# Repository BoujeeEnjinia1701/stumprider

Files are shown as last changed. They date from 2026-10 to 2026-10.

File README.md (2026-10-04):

# StumpRider

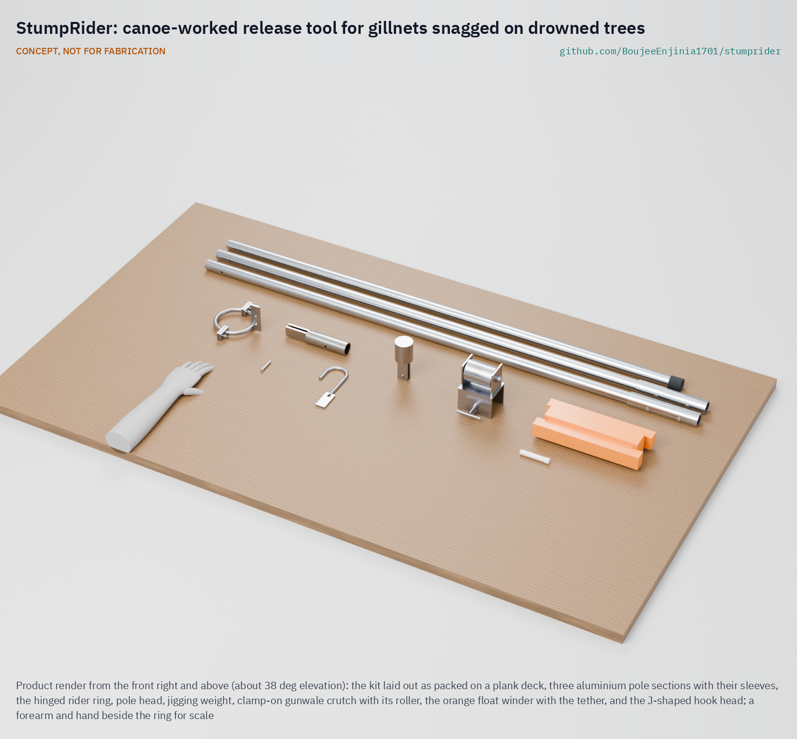
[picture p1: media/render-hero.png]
StumpRider: canoe-worked release tool for gillnets snagged on drowned trees


     

**Area:** Food and water security · **TRL:** 3 of 9 (proof of concept on paper) · **Value-engineering target:** USD 2,000 for the prototype work (estimated cost of the constructable design USD 299.50 for three kits and a bamboo pole) · **Difficulty:** 2 of 5

Frees gillnets snagged on submerged trees from the canoe so children are not sent to dive.

> CONCEPT, NOT FOR FABRICATION. StumpRider is a TRL 3 design on paper: it has not been built or tested, it is not certified equipment, and it never replaces a life jacket.

## Concept rationale

StumpRider is a release tool worked entirely from the canoe. A ring clips around the net line and slides down it onto the snag. The fisher pushes and works the ring with a pole until the net lifts clear of the branch. A shear pin in the pole head breaks at a set load, so a hard pull cannot capsize the canoe or tear the mesh; the pin is replaced and the fisher tries again from a different angle.

The design is deliberately simple: a hinged steel ring, a three-piece pole, a soft aluminium pin and some cord, all of which a village workshop can make and repair. The aim is not to improve the catch but to remove the one task that puts a child underwater. It is published as an open engineering reference so that NGOs, fisheries officers and boat builders can make it locally.

## Burning platform

Lake Volta in Ghana was formed over a flooded forest. It holds about 14 million cubic metres of submerged hardwood, and many trunks lurk just below the surface, where they snag fishermen's nets and hole canoes; stumps were the leading cause of documented boat accidents on the lake from 1990 to 2011, at 38 % ([Underwater timber harvesting on the Volta Lake, WMU](https://commons.wmu.se/cgi/viewcontent.cgi?article=1009&context=all_dissertations)). Child labour studies list the task directly: children dive into deep water to disentangle fishing nets from tree stumps, and small children have drowned doing it ([Analytical study on child labour in Lake Volta fishing, ILAB](https://www.dol.gov/sites/dolgov/files/ILAB/CHILD%20LABOUR%20IN%20VOLTA%20LAKE%20FISHING%20STUDY%20REPORT%20-%20FINAL%20REPORT.pdf)).

A 2024 prevalence study found that 15 % of children working in Lake Volta fishing reported diving underwater to retrieve nets, 37.7 % were likely victims of trafficking, and 5.1 % of parents and caregivers knew of a child who had died working on the lake ([IJM, 2024](https://ijmstoragelive.blob.core.windows.net/ijmna/documents/studies/2023-Fishing_Prevalence_Study_Report.pdf)). Enforcement and rescue matter most, but as long as nets snag, somebody is sent down. A tool that frees the net from the surface takes away the reason to send a child.

## Where it could be used

### By industry

| Industry | Use |
| --- | --- |
| Inland capture fisheries | Freeing gillnets and set lines snagged on drowned trees in reservoirs and lakes |
| Child protection and anti-trafficking programmes | A practical tool to hand out alongside rescue and awareness work, so boat owners have no excuse to send a child to dive |
| Fisheries extension and co-management | Safe-practice kits distributed through fisher associations and landing-site committees |
| Reservoir and dam operators | A low-cost measure for fishing communities on impoundments where forest was left standing |
| Recreational and research netting | Recovering survey nets and sampling gear from snag-rich water without divers |

### By country or region

| Country or region | Why it matters there |
| --- | --- |
| Ghana (Volta Lake) | About 14 million cubic metres of submerged trees snag nets and hole canoes ([WMU](https://commons.wmu.se/cgi/viewcontent.cgi?article=1009&context=all_dissertations)), and 15 % of children in the lake fishery report diving to retrieve nets ([IJM, 2024](https://ijmstoragelive.blob.core.windows.net/ijmna/documents/studies/2023-Fishing_Prevalence_Study_Report.pdf)). |
| Ghana (national) | An ILAB-funded study estimated over 49,000 children involved in fishing in Ghana, 87 % of them boys ([ILAB](https://www.dol.gov/sites/dolgov/files/ILAB/CHILD%20LABOUR%20IN%20VOLTA%20LAKE%20FISHING%20STUDY%20REPORT%20-%20FINAL%20REPORT.pdf)). |
| Zambia and Zimbabwe (Lake Kariba) | A large inshore gillnet fishery on a dammed reservoir, with around 1,200 fishers on the Zambian side by 1999 ([FAO](https://www.fao.org/4/y5056e/y5056e03.pdf)); whether snags drive diving there is an open question. |
| Low- and middle-income countries generally | Small-scale fisheries produce about 99.7 % of inland fisheries output and about 60 million people work in small-scale fishing ([Nature](https://www.nature.com/articles/s41586-024-08448-z)), so a hand tool that works in snag-rich water has a wide potential reach. |

## What sparked the idea

The idea came from the story of Foli, a boy enslaved on Lake Volta who was forced to dive into dark, murky water to untangle nets that caught on branches below the surface, even though he could not swim, until IJM social workers and local authorities took him off the canoe and arrested the boat master ([IJM](https://www.ijm.org/stories/foli)). The net had to come free somehow; the question was whether it could come free without a child going under.

## Problem

On lakes with drowned forests, gillnets catch on submerged trees and boat masters send children down to free them, sometimes children who cannot swim. Fishers have no simple tool that frees a snagged net from the canoe.

Full problem statement: [docs/01-problem.md](docs/01-problem.md)

## Concept

A release tool worked from the canoe that slides a ring down the net line onto the submerged snag and frees the gillnet with a pole and a shear pin, so fishers stop sending children to dive for it.

Full design precis: [docs/02-concept.md](docs/02-concept.md) · Requirements: [docs/03-requirements.md](docs/03-requirements.md) · Calculations: [docs/04-calcs/01-sizing.md](docs/04-calcs/01-sizing.md) · Prototype build plan: [docs/05-build-plan.md](docs/05-build-plan.md) · Design decisions: [docs/06-design-decisions.md](docs/06-design-decisions.md)

## Key components

- Rider ring: two hinged half rings of 12 mm steel bar, 100 mm inside, closed by a pinned gate
- Three-piece aluminium push pole, 4.18 m from the top hand to the ring, packing to 1.55 m
- Pole head with a fork over the ring's tang and a 2 mm soft aluminium shear pin (about 300 N)
- Spare shear pins from one calibrated reel
- 10 m tether cord on an orange foam float winder
- Jigging weight that pins to the ring for snags beyond pole reach
- Clamp-on gunwale crutch with a roller for the net line

## Building the prototype

The [prototype build plan](docs/05-build-plan.md) (SMR-BLD-001, plan, not yet built) is written for a village smith. It covers the kit component by component, with making sketches for the eleven made parts and the bamboo local variant pole, close-ups of eleven joints and a picture for each of twelve assembly steps. The steel parts are bent, cut, drilled and stick-welded, then galvanised; the pole is cut and drilled aluminium tube; everything is made in about a working day. No kit is used on a snag before its pin wire is calibrated on CalRig and a moored heel test shows the canoe stays within 5 deg, which is TRL 4 work.

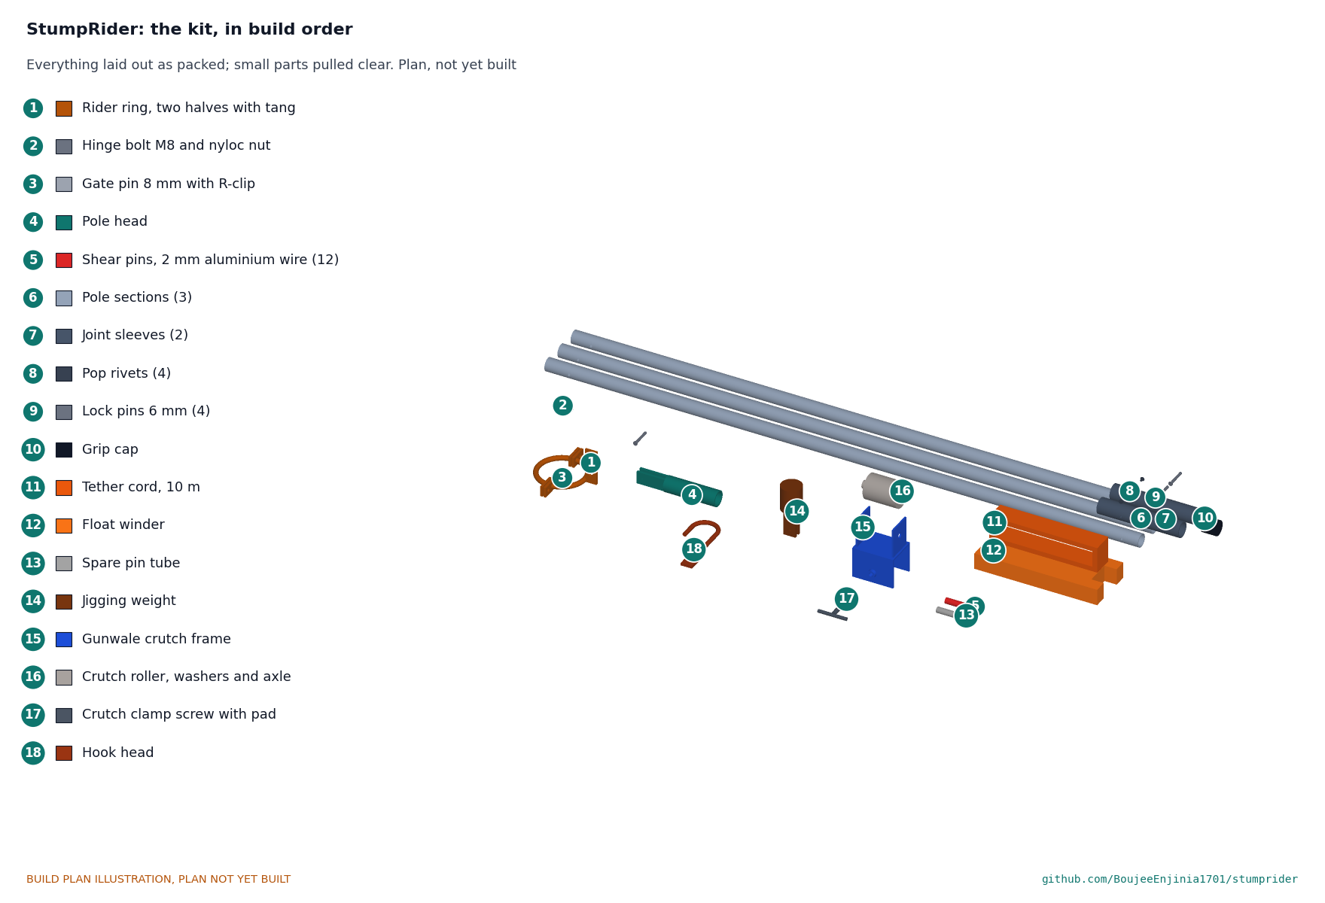
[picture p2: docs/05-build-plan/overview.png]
StumpRider build overview


## Safety

> Published as an open engineering reference, not certified equipment.
>
> The tool exists so that nobody enters the water; it must never be presented as a reason to keep children on boats.
>
> Crew wear life jackets while working a snag; the tool never replaces a life jacket.
>
> The shear pin is a safety device: always use the rated pin, never a nail or bolt substitute.
>
> Stop and cut the net rather than risk a capsize.
>
> The shear pin protects a canoe of about 8 m with three crew; it does not protect small dugouts. The tool is used only from canoes 7 m or longer with at least three crew, until heel tests set a pin for a smaller class, and the operator kneels.
>
> This design is published as an open engineering reference. It is not certified equipment.

## Repository layout

| Folder | Contents |
| --- | --- |
| `docs/` | Problem, concept, requirements, calculations and design decisions |
| `cad/src/` | build123d Python source, the source of truth for all geometry |
| `cad/step/`, `cad/stl/` | Exported models for FreeCAD, other CAD tools and printing |
| `cad/drawings/` | 2D sketches and dimensioned drawings |
| `bom/` | Bill of materials |
| `electronics/` | KiCad schematics and PCB layouts |
| `firmware/` | Microcontroller code |
| `media/` | Renders, perspectives and photos |
| `build-log/` | Dated prototyping notes |

## Documentation

Controlled documents follow the portfolio [documentation standard](.kit/STANDARDS.md). Each carries a document ID (SMR-PRC-001 for the precis), a version and a revision history. Branded PDFs are built with `python .kit/render.py` and attached to GitHub Releases when a document is tagged, for example `SMR-PRC-001/v1.0`.

## Credits

Designed by Amish Chadha at Design Molecule Labs. See [CONTRIBUTORS.md](CONTRIBUTORS.md) for roles. To cite this design, use [CITATION.cff](CITATION.cff) (GitHub shows it as "Cite this repository").

AI assistance (Claude) was used to accelerate prototype documentation and first-pass research. Design direction and all decisions are Amish Chadha's, recorded in this repository's decision records (`docs/decisions/`).

## Licenses

- **Hardware** (CAD, drawings, BOM, electronics): [CERN-OHL-S v2](LICENSE)
- **Software** (firmware, scripts, notebooks): [MIT](LICENSE-SOFTWARE)

A project of the [Design Molecule](https://designmolecule.com) lab.

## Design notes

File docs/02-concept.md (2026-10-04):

---
doc_id: SMR-PRC-001
title: StumpRider design precis
project: StumpRider
doc_type: Precis
version: "0.4"
status: Draft
date: '2026-10-03'
author: Amish Chadha
license: CERN-OHL-S-2.0
revisions:
- version: "0.1"
  date: '2026-09-30'
  author: Amish Chadha
  change: Initial scaffold
- version: "0.2"
  date: '2026-10-03'
  author: Amish Chadha
  change: TRL 2 precis; how it works, components with BOM numbers, key design choices, first-order numbers, safety, open questions
- version: "0.3"
  date: '2026-10-03'
  author: Amish Chadha
  change: TRL 3; constructable design of SMR-DDR-002 and figures from SMR-CAL-001
- version: "0.4"
  date: '2026-10-03'
  author: Amish Chadha
  change: Amish's decisions of 2026-10-03 (SMR-DDR-003); hook head, small-canoe rule, carried kit, bamboo local variant; figures from SMR-CAL-001 v0.2
---

# StumpRider design precis

Frees gillnets snagged on submerged trees from the canoe so children are not sent to dive.

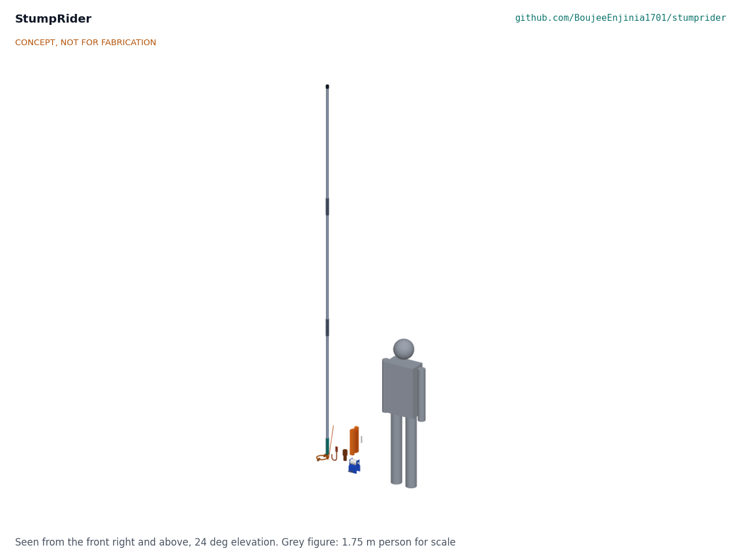
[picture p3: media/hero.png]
StumpRider concept: the tool beside a 1.75 m person, with the gunwale crutch, float winder and jigging weight


*Figure 1. The kit (concept render, CONCEPT, NOT FOR FABRICATION).*

> **Safety:** StumpRider exists so that nobody enters the water. It must never be presented as a reason to keep children on boats, and it never replaces a life jacket. Working a snag pulls the canoe over; the shear pin breaks before the pull can heel the design canoe more than about 4 deg, but small dugouts are not covered (see Safety). Stop and cut the net rather than risk a capsize.

## How it works

The crew pulls the net line up over the gunwale crutch and holds it taut above the snag. The operator, kneeling near the bow, opens the gate of the rider ring, closes the ring round the line and pushes it down the line with the jointed pole until it seats on the branch. The crew then slackens the line and the operator lifts, twists and pushes the ring along the branch until the mesh lifts clear. The pole head grips the ring by a fork on a tang, joined only by a 2 mm soft aluminium shear pin; if the pull or push goes above about 300 N (67 lbf), the pin breaks and the pole comes away. The ring stays on the net line and is recovered on its tether cord, a new pin is fitted, and the operator tries a different angle. For snags beyond the pole's reach, the pole head is taken off, the jigging weight is pinned to the tang in its place, and the ring is run down the line on its tether and jigged, as angling retrievers do.

## Components

*Table 1. Components (numbers are BOM lines in `bom/bom.csv`).*

| # | Component | Role | Made or bought |
| --- | --- | --- | --- |
| 1 | Rider ring | Two half rings of 12 mm steel bar, 100 mm inside, with ears at each joint and a tang on the fixed half; closes round the net line and slides down it | Made: bent, welded, galvanised |
| 2 | Hinge bolt | M8 bolt with a nyloc nut; the swinging half turns on it | Bought |
| 3 | Gate pin | 8 mm clevis pin, R-clip and lanyard; the only part removed to open the ring | Bought |
| 4 | Pole head | Steel socket on the pole with a fork that straddles the tang | Made: welded, galvanised |
| 5 | Shear pins | 2.0 mm soft aluminium wire, 30 mm long; the safety link between fork and tang | Made: cut from one calibrated reel |
| 6 | Pole sections | Three 1.45 m lengths of 32 x 2 mm aluminium tube | Made: cut and drilled |
| 7 | Joint sleeves | 200 mm of 38 mm tube riveted on the lower section of each joint | Made |
| 8 | Pop rivets | Fix the sleeves | Bought |
| 9 | Lock pins | 6 mm clevis pins at the two joints, the head and the jigging weight | Bought |
| 10 | Grip cap | Rubber cap on the top of the pole | Bought |
| 11 | Tether cord | 10 m of 6 mm braided polyester, tied to the tang | Bought |
| 12 | Float winder | Closed-cell foam winder that floats the ring and cord if dropped | Made |
| 13 | Spare pin tube | Keeps eleven spare pins dry | Bought |
| 14 | Jigging weight | 1.1 kg steel weight pinned to the tang for snags beyond pole reach | Made: welded, galvanised |
| 15 | Gunwale crutch frame | Steel saddle clamped on the gunwale, with cheeks for the roller | Made: bent, welded, galvanised |
| 16 | Crutch roller and axle | HDPE roller on an M12 bolt; the net line runs over it | Made and bought |
| 17 | Crutch clamp screw | M10 screw with a pad; clamps gunwales 30 to 60 mm thick | Made |
| 21 | Hook head | 10 mm steel J hook on a flat that pins into the same fork; pulls a wrapped net back round the branch | Made: bent, welded, galvanised |
| V1, V2 | Bamboo local variant pole | Three treated bamboo culms and two steel ferrules in place of lines 6, 7, 8 and 10 (`bom/bom-bamboo-variant.csv`) | Made |

## Key design choices

Each choice was made under Amish's 2026-10-03 pre-approval and is argued in SMR-DDR-001 (TRL 2 review) and SMR-DDR-002 (design for construction); the register is SMR-DEC-001.

- **A hinged ring, not a spring clip.** Two half rings on a hinge bolt, closed by a pinned gate. Nothing springs or corrodes shut, and the ring opens wide enough for any line from 4 to 16 mm.
- **The shear pin is the only link between pole and ring.** The tang never reaches the end plate (45 mm clear), so push and pull both go through the pin, and twisting goes through the fork cheeks bearing on the tang, not the pin.
- **One pin rating, set by the canoe.** 2.0 mm soft aluminium wire in double shear, 302 N nominal; the band allowed by R3 (256 to 347 N) is checked by breaking ten pins from each reel on CalRig before use.
- **Aluminium pole for the prototype, bamboo for local production.** The aluminium pole is uniform, so the trials measure the tool and not a piece of bamboo. Amish decided on 2026-10-03 (SMR-DDR-003) that a bamboo local variant, with one crutch and jigging weight shared by five canoes, is built alongside it so the two can be compared.
- **A hook head for wrapped nets.** A J hook on a flat like the tang pins into the same fork with the same pin, so it adds a second way to unwind a wrap without adding pull on the canoe (SMR-DDR-003).
- **Only canoes 7 m or longer with three crew.** The rule is kept; heel tests by canoe size class at TRL 4 set a pin for each class before a smaller class is served (SMR-DDR-003).
- **Crutch on the canoe, weight at the landing.** The crutch stays clamped on as a fitting and the jigging weight is taken out only for deep sets, so less is carried (SMR-DDR-003).
- **The jigging weight pins to the tang.** A weight loose on the cord would not move the ring; pinned on, it makes the ring heavy enough to jig on the tether.
- **Clamp-on crutch.** It fits any gunwale from 30 to 60 mm thick without drilling the canoe.

## First-order numbers

All from SMR-CAL-001 (`docs/04-calcs/sizing.py`, results in `docs/04-calcs/results.csv`); estimates on stated assumptions, not test results.

*Table 2. Key figures.*

| Quantity | Value | Assumption |
| --- | --- | --- |
| Shear pin rating | 302 N nominal (256 to 347 N) | Soft aluminium wire, 48 MPa in shear, double shear |
| Pull to lift a hooked net | 81 to 126 N | Half a turn on the branch, friction 0.3 to 0.5, crew slackens to 30 N |
| Pull to lift a net wrapped once round | 368 N to 2.3 kN | Same, one and a half turns: above the pin, so it must be worked round first |
| The same, worked back half a turn with the hook head | 162 to 493 N | One full turn left on the branch |
| Design canoe heel when the pin breaks | 3.4 deg kneeling, 4.4 deg standing | 8 m plank canoe, three crew, 550 kg; pin at the top of its band |
| Small dugout heel when the pin breaks | 24 deg kneeling | 5.5 m dugout, two crew, 280 kg; why canoes under 7 m are excluded |
| Top hand to ring | 4.18 m | Hands 300 mm below the top of the pole |
| Ring depth reached with the pole | 3.2 m | Pole 20 deg off vertical, operator kneeling |
| Tether reach, jigging | 8 m | 10 m cord, 2 m kept above the water |
| Pole buckling factor | 2.2 | Euler, 4.35 m, pinned ends, against 347 N |
| Carried kit | 4.28 kg aluminium prototype; 3.89 kg bamboo local variant | Crutch on the canoe, weight at the landing; whole kit 6.78 kg |
| Bamboo pole buckling factor | 1.5 | E 15 GPa; culms chosen by a bend test |
| Parts cost of one kit | USD 95.50 aluminium prototype; USD 54.90 bamboo local variant | Prototype prices; variant with crutch and weight shared by five canoes |

## Patent design-arounds

From the preliminary patent, trademark and prior-art screen (not legal advice), kept unchanged:

- The sliding-ring release is public prior art (US3464138A, expired); keep to a plain split ring and publish our own shear-pin value rather than copying a retail retriever.
- State the child-labour context factually and with sources, without naming individual boat owners or communities.

## Shared blocks

- CalRig proof-load: calibrates each reel of pin wire (ten pins must break within 256 to 347 N).
- LevelHull canoe stability data, where available: replaces the assumed design canoe in the heel check.

## Safety

> **Safety:** These hazards apply to every use and every test of the tool.

- **Nobody enters the water.** The tool is never a reason to keep children on boats; it is handed out only with child-protection work (SMR-DDR-001, D9).
- **Capsize.** The pin limits the pull; in the design canoe it breaks at about 4 deg of heel. In a small dugout the same pin would let the canoe heel about 24 deg, so the tool is used only from canoes 7 m or longer with at least three crew. Amish decided on 2026-10-03 to keep this rule and to set a pin per canoe class from heel tests at TRL 4.
- **The hook head** is held by the same calibrated pin as the ring; it is used kneeling, with the crew's line slack, like the ring.
- **Life jackets** are worn by every person on the canoe while a snag is worked.
- **Use the rated pin only.** Never a nail, bolt or steel wire: a stronger pin removes the protection.
- **Sudden release.** When the pin breaks the operator falls back into the canoe; kneel, never stand, and keep the other crew clear of the pole top.
- **Cut, do not risk it.** If the net will not come free, cut it.

This design is published as an open engineering reference. It is not certified equipment.

## Open questions

Open questions are kept in the design decisions register (SMR-DEC-001): R1, R3, R7 and R10 were decided by Amish on 2026-10-03; one new question on the aluminium prototype's carried mass is open, with the items to confirm when parts are bought.

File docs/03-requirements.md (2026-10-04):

---
doc_id: SMR-REQ-001
title: StumpRider requirements
project: StumpRider
doc_type: Requirements
version: "0.5"
status: Draft
date: '2026-10-04'
author: Amish Chadha
license: CERN-OHL-S-2.0
revisions:
- version: "0.1"
  date: '2026-09-30'
  author: Amish Chadha
  change: Initial scaffold
- version: "0.2"
  date: '2026-10-03'
  author: Amish Chadha
  change: TRL 2; targets kept, design canoe and snag cases defined, concept status for each requirement
- version: "0.3"
  date: '2026-10-03'
  author: Amish Chadha
  change: TRL 3 status from SMR-CAL-001 on the constructable design; R1, R3, R7 and R10 not met or at risk, each a decision for Amish
- version: "0.4"
  date: '2026-10-03'
  author: Amish Chadha
  change: Amish's decisions of 2026-10-03 (10B, 11A then C, 12A, 13C; SMR-DDR-003) carried out; R3 and R7 restated, R10 verification on the local variant; status from SMR-CAL-001 v0.2
- version: "0.5"
  date: '2026-10-04'
  author: Amish Chadha
  change: "R7 judged on the bamboo local variant (round-3 decision 2A, SMR-DDR-004); the aluminium prototype's 4.28 kg is recorded, not a failure of R7"
---

# StumpRider requirements

Targets are unchanged from the scaffold. On 2026-10-03 Amish said: "i agree with all the 46 recommendations you provided. please proceed." This decided R1 (10B, a hook head), R3 (11A then C), R7 (12A) and R10 (13C), recorded in SMR-DDR-003. As a result R3 is restated to name the canoes it covers, R7 is restated to apply to the kit carried to and from the canoe, and R10 is verified on the bamboo local variant. Status is on paper at TRL 3, from the calculation note SMR-CAL-001 v0.2; tags in brackets point to its results. On 2026-10-04 Amish decided option 2A on the aluminium prototype's carried mass: "For round 3, I agree with all your proposed recommendations". R7 is judged on the bamboo local variant (3.89 kg, met); the aluminium prototype's 4.28 kg is recorded, not a failure of R7 (SMR-DDR-004). Decisions are in the register SMR-DEC-001.

> **Safety:** R3 is a safety requirement: the shear pin is what keeps the pull from rolling the canoe. Nothing here relaxes the rules that nobody enters the water and that every person on the canoe wears a life jacket.

*Table 1. Requirements and TRL 3 status.*

| ID | Requirement | Target | Verification (TRL 3 or later) | TRL 3 status |
| --- | --- | --- | --- | --- |
| R1 | Free a gillnet snagged on a submerged branch without anyone entering the water | At least 8 of 10 staged snags freed from the canoe | Tank or shallow-lake trials with staged branches at TRL 4, the hook head tried beside the ring | At risk: hooked nets need 81 to 126 N, well inside the pin [F1, F2]; a net wrapped once round needs 368 N to 2.3 kN [F3, F4], falling to 162 to 493 N once the hook head has worked it back half a turn [F7, F8] |
| R2 | Reach snags at working depth | Pole reach at least 4 m (13 ft); tether-cord method to 6 m (20 ft) | Measured at trial site | Met on paper: 4.18 m from top hand to ring [R1]; tether to 8 m [R3] |
| R3 | Limit side pull on the canoe | Shear pin breaks at a set load within plus or minus 15 % of its rating, below the tested roll load of the canoe it is used from. Used only from canoes 7 m or longer with at least three crew; a smaller canoe class is served only once heel tests at TRL 4 have set a pin for it (restated 2026-10-03, decision 11A then C) | Pull tests on CalRig; heel tests by canoe size class at TRL 4, with a pin diameter set per class | Met on paper where the tool is allowed: design canoe 3.4 deg kneeling, 4.4 deg standing at the top of the band [H5, H6]. A small dugout would heel 24 deg [K5] and is excluded by the rule. The band holds only if each wire reel is calibrated |
| R4 | Protect the net | No more than 5 broken meshes per release on standard 90 to 150 mm mesh | Mesh count after staged releases | Cannot be shown on paper; the pin caps the pull at 347 N [P3] |
| R5 | Fast to use | Median release time under 5 minutes once the snag is found | Timed trials with fisher crews | Cannot be shown on paper |
| R6 | Fit any common net line | Ring clips onto lines and headropes from 4 to 16 mm diameter | Fit check on sample lines | Met on paper: hinged ring, 100 mm inside [R4] |
| R7 | Stows in a canoe | Packed length under 1.6 m (5.2 ft); mass carried to and from the canoe under 4 kg (8.8 lb), with the gunwale crutch left clamped on the canoe and the jigging weight kept at the landing (restated 2026-10-03, decision 12A) | Measurement | Met, judged on the bamboo local variant, 3.89 kg [V3] (decision 2A, 2026-10-04); the aluminium prototype's 4.28 kg [M11] is recorded, not a failure of R7. Packed length 1.55 m [M9] |
| R8 | Survive wet storage | No functional corrosion or rot after 6 months stored wet in a canoe | Field durability check with partner crews | Met on paper: galvanised steel, 6063 aluminium, stainless pins and rivets, polyester, polyethylene; borax-treated bamboo and zinc-painted ferrules in the local variant, to be watched in the field check |
| R9 | Locally buildable | Built by a village workshop from the drawings using hand tools and a small welder in under one day | Build trial with a local smith | At risk: about 8.1 h for one smith with the hook head [T1], galvanising sent out; inside the accuracy of the estimate |
| R10 | Affordable | Parts cost under USD 40 per kit | Costed bill of materials from local prices, on the bamboo local variant with one crutch and jigging weight shared by five canoes (decision 13C) | Not met: USD 54.90 for the bamboo local variant [V8] and USD 95.50 for the aluminium prototype [V9], at prototype prices |

## Assumptions

- Most snags are on branches or trunks within a few metres of the surface, as described on Volta Lake.
- The crew can hold tension on the net line above the snag while the ring is run down, and slacken it while the operator lifts.
- Canoes under 7 m or with fewer than three crew are outside the scope until per-class pins are set (R3).
- Design canoe: 8 m plank canoe, 1.1 m waterline beam, three crew, 550 kg; hard case: 5.5 m dugout, two crew, 280 kg (SMR-CAL-001, section 3). Both are assumptions until measured.
- Boat owners will use a tool if it is faster than sending someone down.

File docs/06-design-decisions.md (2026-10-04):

---
doc_id: SMR-DEC-001
title: StumpRider design decisions register
project: StumpRider
doc_type: Design decisions register
version: "0.3"
status: Draft
date: '2026-10-04'
author: Amish Chadha
license: CERN-OHL-S-2.0
revisions:
- version: "0.1"
  date: '2026-10-03'
  author: Amish Chadha
  change: Register opened; design decisions made under Amish's 2026-10-03 pre-approvals; four requirement decisions proposed, awaiting Amish
- version: "0.2"
  date: '2026-10-03'
  author: Amish Chadha
  change: O1 to O4 decided by Amish (10B, 11A then C, 12A, 13C; SMR-DDR-003); one new open decision on the aluminium prototype's carried mass; items to confirm and value engineering updated
- version: "0.3"
  date: '2026-10-04'
  author: Amish Chadha
  change: O5 decided by Amish (round-3 decision 2A, SMR-DDR-004) and moved to Decisions made; no open decisions
---

# StumpRider design decisions register

Every design decision still to be made, and every decision made, in one place. Each decision is argued in full in its decision record under `docs/decisions/` or in `docs/REVIEW.md`; this register is the index Amish works from. The build plan (`docs/05-build-plan.md`) describes the design as it stands and does not list decisions.

> **Safety:** Several entries set safety limits (the pin rating and its calibration, kneeling, slackening the line, the interim rule on small canoes, life jackets). Each takes the conservative option and names the evidence that would relax it. StumpRider is never a reason to keep children on boats and never replaces a life jacket.

## Open decisions

None. O1 to O4 were decided on 2026-10-03 and O5 (R7 on the aluminium prototype) on 2026-10-04; all are under Decisions made.

## To confirm when parts are bought

These are facts that can only be settled with real parts, a real canoe or the first partner. None changes a decision; each may change a size or a limit.

*Table 2. Items to confirm.*

| # | What to confirm | Why it matters | Source |
| --- | --- | --- | --- |
| 1 | Shear strength of the chosen wire reel (48 MPa assumed): ten pins broken on CalRig | Pin rating and its band (R3) | SMR-CAL-001, A1; SMR-DDR-002, A2 |
| 2 | 38 mm tube with a 32.4 mm bore, or how much opening 38 x 3 tube needs | Sleeve fit | SMR-DDR-002, A1 |
| 3 | Size, mass and crew of the partner's canoes; gunwale thickness and clear side depth | Heel check (R3) and crutch fit | SMR-CAL-001, A2 to A5; SMR-DDR-002, A3 and A4 |
| 4 | How often nets hook and how often they wrap, from partner crews; how hard the hook head must pull to work a wrap back half a turn | R1 and the hook head | SMR-PRB-001; SMR-DDR-003 |
| 5 | Friction of the partner's netting on wet bark (0.3 to 0.5 assumed) | Freeing pull (R1) | SMR-CAL-001, A7 |
| 6 | Local prices for aluminium tube, bamboo, steel tube, galvanising and foam near the first fishery | R10 on the bamboo local variant | `bom/bom.csv`, `bom/bom-bamboo-variant.csv` |
| 7 | Bent ring holds 112 mm mean diameter within 2 mm | Joint gaps and ear alignment | SMR-DDR-002, A5 |
| 8 | Mesh damage at the pin rating on 90 to 150 mm mesh | R4 | SMR-REQ-001 |
| 9 | Stiffness of local bamboo culms: each culm passes the bend test (5 kg at the middle of a 1.4 m span sags 2.9 mm or less); culm diameters 34 to 38 mm slide in the 37 mm ferrule | Bamboo pole buckling (factor 1.49 at E 15 GPa, 1.0 at 10 GPa) | SMR-CAL-001 [V5], [V6], [V10]; SMR-DDR-003 |
| 10 | Borax and boric acid treatment and zinc-painted ferrules hold up for 6 months wet | R8 on the bamboo local variant | SMR-DDR-003 |
| 11 | Canoe size classes at the partner's landings and a measured pin for each class (heel tests at TRL 4) | R3 for canoes under 7 m | SMR-DDR-003 |
| 12 | Workshop time for one kit with the hook head (8.1 h estimated against one day) | R9 | SMR-CAL-001 [T1] |

## Value engineering

Value-engineering target: USD 2,000 (a hypothetical control target, not a limit). Estimated cost of the constructable design: USD 299.50 for the prototype run of three aluminium kits, one bamboo pole set and calibration wire (USD 1,700.50 under the target). One aluminium prototype kit is USD 95.50 with the hook head; one bamboo local variant kit with the crutch and weight shared by five canoes is USD 54.90. Main cost drivers and savings worth trying:

- In the aluminium kit the largest lines are the pole, sleeves and rivets (30 %), galvanising (13 %) and the crutch (13 %); the bamboo local variant removes the first and shares the third.
- Savings still worth trying on the local variant: galvanising a batch of kits together, which spreads the galvaniser's minimum lot; zinc-rich paint only where no galvaniser is near (about USD 9, at some risk to R8); local prices for bamboo and steel tube.
- Smith's labour (about 8.1 hours a kit) is not in the parts cost; a partner workshop making kits in batches would cut it.

## Decisions made

*Table 3. Decisions made.*

| Date | Decision | Decided by | Record |
| --- | --- | --- | --- |
| 2026-10-03 | TRL 2 review items D1 to D10: hinged two-half ring with a pinned gate; three-section aluminium pole for the prototype; one shear pin rating, 2.0 mm soft aluminium, 302 N nominal, calibrated per reel; the pin carries push and pull; operating rules (kneel, slacken, life jackets, tether tied off, cut rather than capsize, interim rule on canoes under 7 m); jigging weight pinned to the tang; foam float winder; clamp-on roller crutch; handed out only through child-protection partners, first candidates to approach (Challenging Heights, a Volta landing-site committee through the Fisheries Commission, a Ghanaian university fisheries department; none approached); requirement targets kept | Amish, pre-approval of 2026-10-03: "start with the first 14 repos from the list of 29 projects. I pre-approve the batch runs along with any recommendations you come up with. I also accept any cost overruns or variations from the assumed scope cost." and "Proceed with the remaining 15 scaffolds" | SMR-DDR-001 |
| 2026-10-03 | Design for construction, changes C1 to C12, and assumptions A1 to A5 | Amish, same pre-approvals | SMR-DDR-002 |
| 2026-10-03 | Safety stops S1 to S5 and the first checks, including pin calibration and a moored heel test before any use on a snag (conservative; a gate, not relaxed) | Amish, same pre-approvals | SMR-BLD-001, sections 5 and 6 |
| 2026-10-03 | O1 (R1, 10B): add a hook head that pins into the same fork (about USD 3), with the unwinding technique taught. O2 (R3, 11A then C): keep the rule (canoes 7 m or longer, three crew) and plan heel tests by canoe size with a pin per class at TRL 4. O3 (R7, 12A): the crutch stays clamped on the canoe and the jigging weight at the landing (4.02 kg carried as proposed; 4.28 kg as built with the hook head and corrected masses). O4 (R10, 13C): a bamboo-pole local variant with a shared crutch and weight (USD 52.90 as proposed; USD 54.90 with the hook head) beside the aluminium prototype | Amish, 2026-10-03: "i agree with all the 46 recommendations you provided. please proceed." | SMR-DDR-003 |
| 2026-10-03 | Appearance model departures for the renders: a plank deck and a forearm and hand beside the packed kit; a short net line over a branch and a cut-short pole for the detail view; the shear pin shown red | Amish, same pre-approvals | docs/REVIEW.md, TRL 3 section |
| 2026-10-04 | O5, R7 (2A): keep the 32 x 2 aluminium pole; R7 is judged on the bamboo local variant (3.89 kg, met); the aluminium prototype's 4.28 kg is recorded, not a failure of R7; the prototype is weighed at TRL 4 | Amish: "For round 3, I agree with all your proposed recommendations" | SMR-DDR-004 |

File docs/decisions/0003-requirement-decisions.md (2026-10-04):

---
doc_id: SMR-DDR-003
title: StumpRider requirement decisions on wrapped nets, small canoes, kit mass and kit cost (R1, R3, R7, R10)
project: StumpRider
doc_type: Design decision record
version: "0.1"
status: Draft
date: '2026-10-03'
author: Amish Chadha
license: CERN-OHL-S-2.0
revisions:
- version: "0.1"
  date: '2026-10-03'
  author: Amish Chadha
  change: Amish's requirement decisions 10B, 11A then C, 12A and 13C carried out
---

# 0003: Hook head, small-canoe rule, carried kit and bamboo local variant (R1, R3, R7, R10)

- **Date:** 2026-10-03
- **Status:** accepted
- **Decided by:** Amish Chadha, 2026-10-03: "i agree with all the 46 recommendations you provided. please proceed." For StumpRider these are decisions 10B (R1), 11A then C (R3), 12A (R7) and 13C (R10), each as recommended in `docs/REVIEW.md` (TRL 3, D-A1 to D-A4).

> **Safety:** The hook head is held by the same calibrated shear pin as the ring, so it cannot pull the canoe over any further than the ring can. The rule that the tool is used only from canoes 7 m or longer with at least three crew is kept; smaller canoes are served only after heel tests set a pin for their class. The bamboo pole changes nothing in the pin, the head or the canoe loads. Nobody enters the water; every person wears a life jacket; the operator kneels.

## Context

At TRL 3 (SMR-CAL-001 v0.1) four requirements fell short: a net wrapped once round a branch needs 368 N to 2.3 kN, above the 256 to 347 N pin band (R1); the same pin would heel a 5.5 m dugout about 24 deg (R3); the whole kit weighed 6.5 kg against 4 kg (R7); and a kit cost USD 92.50 against USD 40 (R10).

## Options considered

- **R1 (D-A1):** A, technique only; **B (chosen), a hook head that pins into the same fork, with the unwinding technique taught**; C, a stronger pin (rejected on heel).
- **R3 (D-A2):** **A (chosen now), keep the rule: canoes 7 m or longer, three crew**; B, a 1.4 mm light pin (still 12 deg in the dugout); **C (chosen for TRL 4), heel tests by canoe size class with a pin per class**.
- **R7 (D-A3):** **A (chosen), the crutch stays clamped on the canoe and the jigging weight stays at the landing**; B, A with bamboo; C, weight left out only.
- **R10 (D-A4):** A, bamboo only; B, sharing only; **C (chosen), a bamboo-pole local variant with a crutch and weight shared by five canoes, beside the aluminium prototype**.

## Decision

1. **Hook head (R1), BOM line 21, making sketch SMR-DWG-111.** A 6 x 28 flat, 60 mm long, with the tang's 10.5 mm tether hole and 2.1 mm shear pin hole, and a 10 mm steel bar bent into a J below it (30 mm bend radius, 50 mm clear throat), welded and galvanised; 0.21 kg, USD 3. In use the shear pin is drawn, the fork is lifted off the ring's tang and put over the hook head's flat, and a calibrated pin is fitted; the tether's bowline is moved to the hook head so it comes back if the pin breaks. The hook pulls the bight of net back round the branch half a turn at a time, then the ring lifts it off. The unwinding technique is taught with both the ring and the hook.
2. **Small canoes (R3).** The rule stands and is printed on the pole head: only canoes 7 m or longer with at least three crew. At TRL 4 the partner's canoes are heel-tested by size class, and a pin diameter is set for each class from its heel test; a class is served only once a measured pin suits it. R3 is restated to say so.
3. **Carried kit (R7).** The gunwale crutch stays clamped on the canoe as a fitting and the jigging weight is kept at the landing for deep sets. R7's mass target applies to the kit carried to and from the canoe and is restated to say so.
4. **Bamboo local variant (R10), `bom/bom-bamboo-variant.csv`, making sketch SMR-DWG-112.** Three treated bamboo culms 36 mm outside and 1,450 mm long in place of the aluminium sections, sleeves, rivets and grip cap; two steel ferrules 40 x 1.5 x 160 mm fixed to the lower culm with an M5 bolt and epoxy; the bottom 120 mm of the lowest culm dressed to 31.8 mm for the same pole head; the top culm cut above a node. One crutch and jigging weight serve five canoes at a landing. One bamboo pole set is built alongside the three aluminium prototype kits for TRL 4 so the two can be compared.

## Consequences

- R1: still at risk on paper. Once the hook has worked a wrap back half a turn the lift falls to 162 to 493 N [F7, F8], inside the pin band for low friction; high friction needs two half turns. The TRL 4 staged-snag trials decide.
- R3: met on paper where the tool is allowed (3.4 deg kneeling, 4.4 deg standing in the design canoe); small canoes excluded by rule.
- R7: the bamboo local variant carries 3.89 kg [V3], met. The aluminium prototype carries 4.28 kg [M11], not met. Correction: the 4.02 kg quoted in D-A3 left out the lock pins, rivets and weight pin (about 0.07 kg); the true figure was 4.08 kg, and the hook head adds 0.21 kg. A thinner prototype pole wall is posed to Amish as a new open decision.
- R9: about 8.1 h for one smith with the hook head [T1], at risk by about 5 minutes; the TRL 4 build trial decides.
- R10: USD 54.90 a kit for the bamboo local variant [V8] (USD 52.90 decided, plus the USD 3 hook head, less the USD 1 grip cap the top node replaces); USD 95.50 for the aluminium prototype. Not met at prototype prices; local prices at TRL 4 decide.
- Bamboo stiffness: buckling factor 1.49 with E 15 GPa [V5], 1.0 if E is only 10 GPa [V6]. Culms are accepted by a bend test: 5 kg hung at the middle of a 1.4 m span sags 2.9 mm or less [V10].
- Cost: Value-engineering target: USD 2,000. Estimated cost of the constructable design: USD 299.50 for three aluminium kits, one bamboo pole set and calibration wire (USD 1,700.50 under the target).
- Constructability: 144 of 144 model checks pass, including the hook head in the fork (pin bearing in its hole, cheeks clear, flat 45 mm clear of the end plate, tether loop clear) and the bamboo pole (spigot seated in the head, ferrule slide fit 0.5 mm, bolts and lock pins through, culms butting, packed length 1.53 m).

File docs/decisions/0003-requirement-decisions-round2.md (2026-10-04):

---
doc_id: SMR-DDR-003
title: StumpRider requirement decisions, round 2
project: StumpRider
doc_type: Design decision record
version: "0.1"
status: Draft
date: '2026-10-03'
author: Amish Chadha
license: CERN-OHL-S-2.0
revisions:
- version: "0.1"
  date: '2026-10-03'
  author: Amish Chadha
  change: Amish's decisions on R1 (D-A1 B), R3 (D-A2 A now, C at TRL 4), R7 (D-A3 A) and R10 (D-A4 C) carried into the model, calculations, BOM, drawings and build plan
---

# 0003: Requirement decisions, round 2

- **Date:** 2026-10-03
- **Status:** Decided by Amish Chadha, 2026-10-03: "i approve all of the 47 recommendations provided by you. Execute them." For StumpRider these are the four requirement decisions of SMR-DEC-001 (O1 to O4; portfolio decisions 37 to 40), each decided as recommended.

## Context

At TRL 3 (SMR-CAL-001 v0.1) the constructable design (SMR-DDR-002) left four requirements short. R1: a net wrapped once round a branch needs 368 N to 2.3 kN, above the 256 to 347 N pin band. R3: the pin that protects the 8 m design canoe would heel a 5.5 m dugout 23.7 deg. R7: the whole kit weighed 6.5 kg against 4 kg. R10: a kit cost USD 92.50 against USD 40. The four were put to Amish with options and a recommendation in `docs/REVIEW.md` and SMR-DEC-001. Decisions D-A3 and D-A4 interact: D-A4 C includes the bamboo sections and the shared crutch and weight, and D-A3 A leaves bamboo to be judged under D-A4.

## Options considered

*Table 1. The four decisions put to Amish and the option chosen.*

| # | Requirement | Options | Chosen |
| --- | --- | --- | --- |
| D-A1 | R1, wrapped nets | A: teach walking the ring back round the branch, or cutting. B: add a hook head on a shear-pinned flat. C: a stronger pin | **B**, made and tried beside the ring in the TRL 4 staged-snag trials, with A taught either way |
| D-A2 | R3, small canoes (safety) | A: keep the interim rule (only canoes of 7 m or more with three crew) printed on the pole head. B: a light 1.4 mm pin for 5 to 7 m canoes. C: heel-test canoes by size class at TRL 4 and set a pin per class | **A now, and C in the TRL 4 heel tests** |
| D-A3 | R7, kit mass | A: crutch stays clamped on the canoe, jigging weight at the landing. B: A plus bamboo sections. C: leave out only the weight | **A**, with bamboo judged under D-A4 |
| D-A4 | R10, kit cost | A: bamboo sections with steel ferrules. B: one crutch and weight shared by five canoes. C: A and B together | **C**, as the local production variant built alongside the aluminium prototype at TRL 4 |

## Decision

*Table 2. Each decision as carried into the design. Figures from SMR-CAL-001 v0.2 (`docs/04-calcs/sizing.py`).*

| # | Requirement | Option chosen | Effect on the design | Condition |
| --- | --- | --- | --- | --- |
| D-A1 | R1 | B: hook head | A new made part (`hook_head()` in `cad/src/model.py`, BOM line 21, sketch SMR-DWG-111, joint 10, step 12): a 6 x 28 x 50 mm flat, drilled for the same 2.1 mm shear pin at the tang's shear-pin height and for the tether, with a J hook of 12 mm bar below it, 44 mm throat opening upward. It pins into the pole-head fork in place of the ring, so it pulls with at most the top of the pin band, 347 N [F7], and draws the bight back round the branch half a turn at a time. 0.19 kg, USD 3, about 20 min of the smith's time. Model checks: 86 of 86 pass, including the hook head in the fork | R1 stays **at risk** on paper: whether wraps can be unwound is shown only in the TRL 4 staged-snag trials, where the hook head is made and tried beside the ring and the walking-back technique is taught either way |
| D-A2 | R3 (safety) | A now; C at TRL 4 | The interim rule, "only canoes of 7 m or longer with 3 crew", is lettered on the pole head with the pin rating (BOM line 19 now names it; SMR-DWG-001 Rev P3 note; build plan step 5). No change to the pin | R3 is **met on paper where the tool is allowed**; canoes under 7 m or with fewer than three crew are **not served**. Planned TRL 4 step: heel-test real canoes by size class and set a pin diameter per class from the measured righting moment. Small canoes are served only once a measured pin suits them |
| D-A3 | R7 | A: crutch on the canoe, weight at the landing | No part changes. The gunwale crutch is treated as a fitting left clamped on the canoe; the jigging weight is kept at the landing for deep sets. The kit carried in the canoe is 4.02 kg [O9], and 4.22 kg with the hook head of D-A1 [M11]. The aluminium prototype stays the TRL 3 design | R7 stays **not met on paper, by 0.22 kg**, for the aluminium prototype; the local production variant of D-A4 carries 3.56 kg [O10] and meets it. A new question on R7 is in `docs/REVIEW.md` |
| D-A4 | R10 | C: local production variant | Costed line by line in a new `bom/bom-local-variant.csv`: three bamboo sections about 35 mm with node-closed ends, borax-boric treated (USD 1 each), two pinned steel ferrules in place of the aluminium sleeves and rivets (USD 2 each), and one crutch and jigging weight shared by five canoes at a landing (one fifth a kit, with that share of the galvanising). USD 55.90 a kit with the hook head [C8]. The aluminium prototype (`bom/bom.csv`, USD 95.50) is unchanged in the model and drawings | R10 stays **not met** by either: USD 95.50 for the prototype, USD 55.90 for the variant. The variant is built alongside the aluminium prototype at TRL 4 so the two can be compared; bamboo stiffness and rot protection are checked there; local prices and batch galvanising may bring it nearer USD 40 |

## Consequences

- `cad/src/model.py` adds the hook head; STEP (`hook-head.step`, assembly), the GA SMR-DWG-001 (Rev P3), the concept media, `media/model.glb`, the build plan overview, the new sketch SMR-DWG-111, joint 10 and step 12 are regenerated from the model.
- SMR-CAL-001 v0.2 is re-run. R1 at risk; R3 met where allowed, small canoes not served; R7 not met by 0.22 kg (prototype), met by the variant; R9 met at the limit (8.0 h with the hook head); R10 not met (USD 95.50; variant USD 55.90).
- Prototype run of three kits and calibration wire: USD 292.50 (was USD 284), USD 1,707.50 under the USD 2,000 value-engineering target; `budget_usd` unchanged.
- New questions (R7 for the aluminium prototype, R9 at its limit) are recorded in `docs/REVIEW.md` and SMR-DEC-001 as **Proposed, awaiting Amish**.

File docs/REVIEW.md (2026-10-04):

# Review note: StumpRider

## Session 2026-09-30: scaffolded

### What was done

- Repository created from kit 1.6.0 at TRL 1, target TRL 2.
- `docs/01-problem.md` (SMR-PRB-001 v0.1): problem with cited evidence, users, environment, constraints, prior work, open questions.
- `docs/02-concept.md` (SMR-PRC-001 v0.1): how it works, components, patent design-arounds, shared blocks, safety.
- `docs/03-requirements.md` (SMR-REQ-001 v0.1): 10 proposed requirements.
- `README.md` with concept rationale, burning platform, where it could be used, and what sparked the idea.

### Next

- Run `/populate` to bring the repo to a strong TRL 2 with concept media.

## Session 2026-10-03: TRL 2 (populate)

Run as the first half of `/to-trl3` under Amish's pre-approvals of 2026-10-03: "start with the first 14 repos from the list of 29 projects. I pre-approve the batch runs along with any recommendations you come up with. I also accept any cost overruns or variations from the assumed scope cost." and "Proceed with the remaining 15 scaffolds". Kit 1.7.0 installed.

### What was done

- `docs/01-problem.md` (SMR-PRB-001 v0.2): design canoe and snag cases, budget written as a value-engineering target, open questions settled or moved to the register, first co-design candidates, safety section.
- `docs/02-concept.md` (SMR-PRC-001 v0.2): how it works, components with BOM numbers, key design choices, first-order numbers, design-arounds kept, safety.
- `docs/03-requirements.md` (SMR-REQ-001 v0.2): R1 to R10, targets unchanged, with a concept status.
- Concept media from `cad/src/concept_media.py`: `media/hero.png` (1.75 m person for scale), `media/exploded.png` (the working end, BOM callouts), `media/cutaway.png` (cut through the shear pin), `media/concept-blueprint.png`, `.pdf` and `.svg` (SMR-DWG-010), `media/model.glb` (0.9 MB, coarse tessellation) and `media/viewer.html`. No flow diagram: the tool moves no energy or material.
- `bom/bom.csv`: 20 priced lines.

### Results

- A ring on a pole can lift a net hooked over a branch with a modest pull; the pin rating that keeps an 8 m canoe safe is about 300 N. A net wrapped round a branch and a small dugout are the two hard cases.

### Requirements not met

- See the TRL 3 section: R1 and R3 at risk, R7 and R10 not met; R4 and R5 cannot be shown on paper.

### Decisions made under the pre-approval

SMR-DDR-001, items D1 to D10: hinged two-half ring; aluminium prototype pole; one calibrated 2.0 mm aluminium shear pin, 302 N nominal; pin carries push and pull; operating rules including the interim rule on canoes under 7 m; pinned jigging weight; foam float winder; clamp-on roller crutch; distribution only through child-protection partners, first candidates to approach (none approached); requirement targets kept.

### Safety concerns

- The tool must never be read as making child diving or child labour acceptable; it is handed out only with child-protection work.
- Capsize when pulling from a small canoe (see TRL 3).

## Session 2026-10-03: TRL 3 (advance and build plan)

Run as the second half of `/to-trl3` under the same pre-approvals, which count as the TRL 2 approval. Not committed or pushed (batch run).

### What was done

- `cad/src/model.py`: parametric build123d model of the kit; 80 of 80 constructability checks pass (overlaps; every pin and rivet bearing in its holes; fork and weight cheeks clear of the tang; tang 45 mm clear of the end plate; sleeve slide fit; sections butting; tether clear of the head and weight; crutch on 30, 40 and 60 mm gunwales; packed length). Exports `cad/step/stumprider-assembly.step`, `rider-ring.step`, `pole-head.step`, `pole-section.step`, `joint-sleeve.step`, `jigging-weight.step`, `gunwale-crutch.step`, `float-winder.step`, and STL of the ring halves, pole head, roller and float winder.
- `docs/04-calcs/01-sizing.md` (SMR-CAL-001 v0.1) with `docs/04-calcs/sizing.py` and `results.csv`: pin rating, canoe heel for the design canoe and a small dugout, freeing pull, reach, strength, float, mass, build time, cost and the option figures below.
- `cad/src/sheets.py`: general arrangement `cad/drawings/SMR-DWG-001` (SVG, PDF, PNG) at Rev P2: the working end in three views at 1:5 and the whole tool at 1:40.
- `cad/src/build_plan_media.py`: `docs/05-build-plan/overview.png`, 10 making sketches `cad/drawings/SMR-DWG-101` to `110`, 9 joint close-ups and 11 step pictures.
- `docs/05-build-plan.md` (SMR-BLD-001 v0.1), `docs/06-design-decisions.md` (SMR-DEC-001 v0.1), `docs/decisions/0001-trl2-review-decisions.md` (SMR-DDR-001) and `docs/decisions/0002-design-for-construction.md` (SMR-DDR-002). SMR-PRC-001 and SMR-REQ-001 updated to v0.3.
- `cad/src/product_model.py` (appearance model) and render scenes exported with `.kit/export_views.py` to `/home/claude/renders/stumprider` for hero, exploded and detail; photoreal renders and cards are made on Amish's Mac.
- `project.yaml`: trl 3, trl_target 3, `design_state: constructable`, evidence listed; `budget_usd` unchanged. README leads with `media/render-hero.png` and has a "Building the prototype" section.

### Results

- Shear pin: 2.0 mm soft aluminium in double shear, 302 N nominal, 256 to 347 N band (to be calibrated per reel).
- Design canoe (8 m, three crew, 550 kg): 3.4 deg of heel kneeling and 4.4 deg standing when the pin breaks at the top of its band; 523 N would be needed for 5 deg.
- Freeing a hooked net: 81 to 126 N, a margin of 2.0 on the bottom of the pin band.
- Reach: 4.18 m top hand to ring; ring 3.2 m deep at 20 deg; tether to 8 m.
- Strength: pole buckling factor 2.2 is the smallest margin; every other part is at least 6 times the pin.
- Float: holds the ring and cord with a reserve of 2.1, not the jigging weight.
- Mass: working tool 3.73 kg, whole kit 6.5 kg. Build time about 7.7 h for one smith.
- Value-engineering target: USD 2,000. Estimated cost of the constructable design: USD 284 for three prototype kits and calibration wire (USD 1,716 under the target); USD 92.50 for one kit.

### Requirements not met or at risk

- R1 at risk (wrapped nets), R3 at risk (small canoes), R7 not met (kit mass), R10 not met (kit cost). Each is posed below for Amish to decide.
- R4 (mesh damage) and R5 (release time) cannot be shown on paper.

### Decisions for Amish

Each is listed in SMR-DEC-001 under Open decisions as "Proposed, awaiting Amish".

**D-A1. R1, freeing a net wrapped round a branch.**
- State: a net hooked over a branch lifts off at 81 to 126 N, inside the pin; a net wrapped once round needs 368 N (low friction) to 2,260 N (high friction), above the 256 to 347 N pin band. Cause: friction grows exponentially with each turn of net on the branch.
- Option A: no change; the crew is taught to walk the ring back round the branch half a turn at a time before lifting, or to cut. Effect: R1 rests on technique, unproven until trials; cost USD 0, mass 0.
- Option B: add a hook head, a bent 12 mm bar hook on a tang-sized flat that pins into the same fork with a shear pin, to pull the bight back round the branch. Effect: a second way to unwind a wrap; cost about USD 3 a kit, mass about 0.2 kg (R7 worse by that much).
- Option C: a stronger pin for wrapped nets. Effect: frees more wraps but heels the design canoe past 5 deg; rejected on safety grounds unless a heel test allows it; cost USD 0.
- **Recommendation: B**, made and tried beside the ring in the TRL 4 staged-snag trials, with the technique of A taught either way.

**D-A2. R3, small canoes.**
- State: in the 8 m design canoe the pin breaks at 3.4 to 4.4 deg of heel; in a 5.5 m two-crew dugout the same pin allows 23.7 deg kneeling, and 53 N already heels it 5 deg. Cause: a small dugout's righting moment is about a ninth of the design canoe's.
- Option A: keep the interim rule (only canoes of 7 m or more with at least three crew), printed on the pole head. Effect: R3 met where the tool is allowed; small canoes not served; cost USD 0.
- Option B: a light pin, 1.4 mm wire (148 N nominal), for canoes of 5 to 7 m. Effect: still 12.2 deg in the small dugout and barely above the pull a hooked net needs; a second reel to calibrate; cost about USD 3.
- Option C: heel-test real canoes by size class at TRL 4 and set a pin diameter per class. Effect: R3 met with evidence for each class; cost the test time and one reel per class.
- **Recommendation: A now, and C in the TRL 4 heel tests**, so small canoes are served only once a measured pin suits them.

**D-A3. R7, kit mass.**
- State: whole kit 6.5 kg (working tool 3.73 kg); packed length 1.55 m meets. Cause: the jigging weight (1.11 kg) and the steel crutch (1.37 kg).
- Option A: the crutch stays clamped on the canoe as a fitting and the jigging weight is kept at the landing for deep sets. Effect: 4.02 kg carried; cost USD 0.
- Option B: A plus bamboo pole sections with steel ferrules. Effect: 3.37 kg; saves about USD 22; bamboo varies in stiffness and needs rot protection (R8).
- Option C: leave out only the jigging weight. Effect: 5.39 kg; cost USD 0.
- **Recommendation: A** for the prototype; bamboo is judged under D-A4.

**D-A4. R10, kit cost.**
- State: USD 92.50 a kit at prototype prices. Cause: aluminium pole and sleeves (31 %), galvanising (13 %) and the crutch (13 %).
- Option A: bamboo pole sections with steel ferrules. Effect: USD 70.50; mass 0.65 kg less; stiffness to be checked.
- Option B: one crutch and jigging weight shared by five canoes at a landing. Effect: USD 74.90 a kit; no change to the tool.
- Option C: A and B together. Effect: USD 52.90 a kit; with local prices and batch galvanising it may come nearer the target.
- **Recommendation: C** as the local production variant, built alongside the aluminium prototype at TRL 4 so the two can be compared.

### Decisions made under the pre-approval

- SMR-DDR-002: design for construction, changes C1 to C12 and assumptions A1 to A5.
- Safety stops S1 to S5 and first checks, including pin calibration and a moored heel test before any use on a snag.
- Appearance model departures (renders only): a plank deck and a forearm and hand beside the packed kit in the hero; a short net line draped over a branch and the pole cut short in the detail view; the shear pin coloured red so it reads.

### Build plan findings

- Design changes for construction (2026-10-03), all in SMR-DDR-002: hinged two-half ring with ears, bolt hinge and pinned gate; steel socket with end plate and fork; tang with three holes, 45 mm clear of the plate; three 1.45 m sections with riveted sleeves and lock pins; removable head; grip cap; bowline tether and notched foam winder; jigging weight pinned to the tang; clamp-on saddle crutch with roller; galvanised steel and stainless pins; 30 mm pins with bent ends; rating and visibility marks.
- Items to confirm with real parts and canoes (wire strength, sleeve tube, canoe data, snag frequency, friction, prices, ring accuracy, mesh damage) are in SMR-DEC-001.

### Safety concerns

- Nobody enters the water, ever; the tool is handed out only with child-protection work and never presented as making child labour safer.
- Capsize: the pin protects the design canoe only. Until heel tests, no use from canoes under 7 m or with fewer than three crew; the operator kneels and the crew slackens the line when lifting.
- The pin is the safety device: only calibrated pins; a nail or bolt removes the protection.
- Sudden release when the pin breaks: the operator kneels so a fall is into the canoe.
- Welding galvanised steel gives off zinc fumes: all welding is done before galvanising, outdoors.
- Safety stops S1 to S5 in SMR-BLD-001 gate welding, fitting pins, going afloat and the first heel test.

### Recommended next step

Amish decides D-A1 to D-A4. The design is then ready for TRL 4 once Amish chooses to start it: build one aluminium kit (and the bamboo variant if D-A4 C is chosen), calibrate a wire reel on CalRig, and run the bench and moored heel checks of SMR-BLD-001 section 5 with the first co-design candidate.

## 2026-10-03: photoreal renders

Rendered with Blender Cycles on Amish's Mac from `cad/src/product_model.py`; captioned with `.kit/photo_caption.py`; `media/card.png` and `media/social-preview.png` made with `.kit/cards.py`. Views: hero, exploded, detail. image_qc passes and `render.py --check` has no FAIL.

## 2026-10-03: Amish's requirement decisions carried out

Amish said on 2026-10-03: "i agree with all the 46 recommendations you provided. please proceed." For StumpRider these are decisions 10B (R1), 11A then C (R3), 12A (R7) and 13C (R10), each as recommended under D-A1 to D-A4 above. Recorded in `docs/decisions/0003-requirement-decisions.md` (SMR-DDR-003). Not committed or pushed (batch run).

### Changes

- `cad/src/model.py`: hook head (BOM line 21): 6 x 28 x 60 flat with the tang's 10.5 and 2.1 mm holes and a 10 mm bar J (R30 bend, 50 mm clear throat), pinned into the same fork with the same shear pin; tether bowline moved across to it in use. Bamboo local variant pole: three 36 x 6 culms, bottom 120 mm dressed to 31.8 mm for the pole head, two 40 x 1.5 x 160 steel ferrules with M5 bolts, same lock pins. 144 of 144 constructability checks pass (64 new: hook head in the fork, pin bearing, cheeks clear, flat 45 mm clear of the plate, tether loop clear, throat; bamboo spigot seated, ferrule slide fit, bolts and pins through, culms butting, packed length; hook head clear of every part in the GA and packed layouts). STEP and STL regenerated, with new `hook-head.step`, `bamboo-pole-variant.step` and `hook-head.stl`.
- `bom/bom.csv` line 21 (hook head, USD 3, price basis given) and new `bom/bom-bamboo-variant.csv` (culms USD 1 each, ferrules USD 2 each, price basis given). `budget_usd` unchanged.
- `docs/04-calcs/sizing.py`, `01-sizing.md` v0.2 and `results.csv`: unwinding stages [F7, F8], hook head mass [M10], carried kits [M11, V3], bamboo pole [V1 to V10], new option figures [N1, N2]; old option figures O1 to O10 removed. Correction: lock pins, rivets and the weight pin had been left out of the masses (about 0.07 kg), because parts grouped inside a group read no volume.
- `docs/03-requirements.md` v0.4: R3 restated (used only from canoes 7 m or longer with three crew; smaller classes once heel tests set a pin), R7 restated (mass carried to and from the canoe, crutch on the canoe, weight at the landing), R10 verified on the bamboo local variant; Amish quoted. `docs/02-concept.md` v0.4, README, `project.yaml` evidence.
- `docs/05-build-plan.md` v0.2: Table 1 rows, sections 3.11 (hook head) and 3.12 (bamboo pole), Step 12 (hook head), Steps 10 and 11 (crutch stays on the canoe, weight at the landing), checks 8 and 9, S4 and S5.
- Pictures: general arrangement SMR-DWG-001 Rev P3 (detail B, hook head, and note lines); new making sketches SMR-DWG-111 (hook head) and SMR-DWG-112 (bamboo culms and ferrule joint); overview regenerated with the hook head; new joint-10 (hook head in the fork), joint-11 (ferrule joint) and step-12; concept media regenerated (hero, exploded, cutaway, blueprint key figures, `model.glb`).
- `docs/06-design-decisions.md` v0.2: O1 to O4 moved to Decisions made; new open decision O5; items to confirm 9 to 12; value engineering re-costed.
- `cad/src/product_model.py`: the hook head in the packed kit of the hero view; scenes re-exported to `/home/claude/renders/stumprider`.

### New results

- R1: at risk. A wrap worked back half a turn by the hook head needs 162 to 493 N [F7, F8] (was 368 N to 2.3 kN); low friction comes inside the pin band after one half turn, high friction after two. The staged-snag trials decide.
- R3: met on paper where the tool is allowed (3.4 deg kneeling, 4.4 deg standing in the design canoe); canoes under 7 m or with fewer than three crew excluded by the rule; pins per canoe class at TRL 4.
- R7 (4 kg carried): bamboo local variant 3.89 kg, met; aluminium prototype 4.28 kg, not met (4.08 kg before the hook head; the 4.02 kg quoted in D-A3 was low by 0.07 kg). Packed length 1.55 m, met.
- R9: about 8.1 h for one smith with the hook head (was 7.7 h), at risk by about 5 minutes against one day.
- R10 (USD 40): bamboo local variant USD 54.90 a kit (USD 52.90 decided, plus the USD 3 hook head, less the USD 1 grip cap), aluminium prototype USD 95.50; not met at prototype prices.
- Bamboo pole: buckling factor 1.49 at E 15 GPa, 1.0 at 10 GPa; culms accepted by a bend test (5 kg at the middle of a 1.4 m span sags 2.9 mm or less).
- Mass: hook head 0.21 kg; whole kit 6.78 kg.
- Value-engineering target: USD 2,000. Estimated cost of the constructable design: USD 299.50 for three aluminium kits, one bamboo pole set and calibration wire (USD 1,700.50 under the target).

### For Amish

**O5. R7 on the aluminium prototype (proposed, awaiting Amish).**
- State: the aluminium prototype carries 4.28 kg, 0.28 kg over R7's 4 kg. The 4.02 kg of D-A3 was really 4.08 kg, and the hook head adds 0.21 kg. The bamboo local variant carries 3.89 kg and meets R7.
- Option A: keep the 32 x 2 aluminium pole; judge R7 on the bamboo local variant and weigh the prototype at TRL 4. Cost USD 0.
- Option B: 32 x 1.6 aluminium tube for the prototype pole. Carried 3.86 kg; buckling factor 1.84 instead of 2.2; cost about the same; the thinner wall dents more easily.
- Option C: restate R7 to 4.3 kg.
- **Recommendation: A**, so the prototype trials stay comparable with the calculation note and R7 is judged on the kit fishers would get.
- The photoreal renders (`media/render-*.png`), card and social preview do not show the hook head yet; re-render on the Mac from the re-exported scenes.

### Safety

- The hook head is held by the same calibrated pin as the ring and is used under the same rules (kneel, slacken the line, cut rather than capsize, life jackets); it cannot heel the canoe more than the ring can.
- The 7 m, three-crew rule stands; a smaller canoe class needs its own heel-tested pin first.
- A bamboo culm softer than assumed bows before the pin breaks; this bends the pole but does not raise the load on the canoe. Culms are bend-tested before use.

## 2026-10-04: Amish's requirement decisions carried out (round 3)

Amish on 2026-10-04: "For round 3, I agree with all your proposed recommendations". For StumpRider this decides O5 of SMR-DEC-001 as recommended (2A). Recorded in `docs/decisions/0004-r7-prototype-mass.md` (SMR-DDR-004). Wording and records only; no geometry. Not committed or pushed.

### Changes

- `docs/03-requirements.md` v0.5: R7 judged on the bamboo local variant; Amish quoted.
- `docs/04-calcs/01-sizing.md`: R7 notes and summary row updated.
- `docs/06-design-decisions.md` v0.3: O5 moved to Decisions made; Open decisions now "None."
- No model, BOM, drawing or media change was needed.

### New results

- R7: met on the bamboo local variant, 3.89 kg carried against 4 kg. The aluminium prototype's 4.28 kg is recorded, not a failure of R7; it is weighed at TRL 4.
- Value-engineering target: USD 2,000. Estimated cost of the constructable design: USD 299.50 (USD 1,700.50 under the target). Unchanged.

### For Amish

Nothing new.

## 2026-10-04: photoreal renders redone after the round-2 and round-3 decisions

Views: hero, exploded, detail; cards regenerated; image_qc passes and `render.py --check` has no FAIL.

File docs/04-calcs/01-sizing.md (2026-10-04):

---
doc_id: SMR-CAL-001
title: StumpRider sizing calculations
project: StumpRider
doc_type: Calculation note
version: "0.2"
status: Draft
date: '2026-10-03'
author: Amish Chadha
license: CERN-OHL-S-2.0
revisions:
- version: "0.1"
  date: '2026-10-03'
  author: Amish Chadha
  change: First issue at TRL 3, on the constructable design of SMR-DDR-002
- version: "0.2"
  date: '2026-10-03'
  author: Amish Chadha
  change: Amish's requirement decisions of 2026-10-03 carried out (SMR-DDR-003); hook head, carried kit, bamboo local variant and shared crutch and weight; masses of lock pins and rivets corrected; option figures replaced
---

# StumpRider sizing calculations

On paper, a 2.0 mm soft aluminium shear pin (302 N nominal) frees a net hooked over a branch with a margin of at least two, and breaks before the pull can heel the 8 m design canoe more than 4.4 deg. The tool reaches 4.18 m from the top hand to the ring and the tether works snags to 8 m. Amish decided R1, R3, R7 and R10 on 2026-10-03 (SMR-DDR-003): a hook head that pins into the same fork for wrapped nets; the 7 m, three-crew rule kept, with a pin per canoe class from heel tests at TRL 4; the crutch left on the canoe and the jigging weight at the landing; and a bamboo local variant beside the aluminium prototype. With those, the bamboo local variant carries 3.89 kg (R7 met) and costs USD 54.90 a kit (R10 not met); the aluminium prototype carries 4.28 kg (R7 not met) and costs USD 95.50; a smith needs about 8.1 h for a kit (R9 at risk). A net wrapped round a branch still needs more pull than the pin until it has been worked back (R1 at risk).

Every figure comes from `docs/04-calcs/sizing.py`, which imports the parametric model (`cad/src/model.py`), so the sizes here are those of the STEP files, the drawings and the build plan. Tags in square brackets match the script output and `docs/04-calcs/results.csv`. These are screening estimates for a paper proof of concept; they do not replace the pin calibration on CalRig, the canoe heel test or the staged-snag trials, which are TRL 4 work.

> **Safety:** The pin rating is a safety limit. It is valid only for pins cut from a reel whose sample has been broken on CalRig within 256 to 347 N, and only for canoes like the design canoe. Until a heel test says otherwise the tool is not used from canoes under 7 m or with fewer than three crew, the operator kneels, and every person wears a life jacket.

## 1. Assumptions

*Table 1. Assumptions.*

| # | Assumption | Value | Basis |
| --- | --- | --- | --- |
| A1 | Shear strength of the pin wire | 48 MPa | 1050 or 1100 aluminium, O temper: about 0.6 of an 80 MPa tensile strength; to be measured per reel |
| A2 | Design canoe | 8.0 m long, 1.10 m waterline beam, 0.60 m deep, hull 300 kg, three crew of 65 kg, 55 kg of net and gear (550 kg) | A paddled Volta plank canoe; to be replaced by LevelHull or partner measurements |
| A3 | Small dugout (hard case) | 5.5 m, 0.75 m beam, 0.45 m deep, hull 120 kg, two crew, 30 kg load (280 kg) | Smallest canoe likely to carry the tool |
| A4 | Canoe hydrostatics | Waterplane transverse moment 0.05 L B^3; block coefficient 0.45; centre of buoyancy at 0.55 of the draft; hull mass centre 0.22 to 0.25 m up; kneeling crew 0.50 to 0.55 m up | Screening values for narrow round-bilged hulls |
| A5 | Working posture | Pole 20 deg off vertical; operator's hands 0.35 m (0.25 m in the dugout) off the centreline and 0.30 m (kneeling) or 0.85 m (standing) above the gunwale | The crutch is clamped near the bow |
| A6 | Net line forces | Crew holds 100 N while the ring is run down and slackens to 30 N while the operator lifts; the far leg of the net pulls 20 N | Operating rule and the net's own drag |
| A7 | Friction of wet netting on wet bark | 0.3 to 0.5 | Range for nylon on rough wood |
| A8 | Materials | Steel 7,850 kg/m3, S235; 6063-T6 aluminium 2,700 kg/m3, E 69 GPa, bearing 320 MPa; stainless clevis pins 300 MPa in shear; 4.8 mm stainless rivet 2.9 kN; HDPE 950; foam 30 kg/m3; cord 25 g/m | Handbook and catalogue values |
| A9 | Heel limit | 5 deg with the pin at the top of its band | Conservative: well short of the 40 deg at which the design canoe's gunwale goes under, and small enough for kneeling crew to keep their balance |
| A10 | Bamboo culm (local variant) | 36 mm outside, 6 mm wall, 700 kg/m3, E 15 GPa along the culm (10 to 20 GPa range) | Seasoned, treated culm; to be checked culm by culm with the bend test in section 10 |

## 2. Shear pin

The pin passes through both fork cheeks and the tang, so it is cut on two planes. Rating = 2 x shear strength x pin area = 2 x 48 MPa x 3.14 mm2 = 302 N nominal [P1]. R3 allows plus or minus 15 %: 256 N [P2] to 347 N [P3]. Every safety check below uses the top of the band; every freeing check uses the bottom.

## 3. Canoe heel

When the operator pulls up on the pole, the pole pulls down and outboard on the operator's hands, and so on the canoe. The heeling moment is the pull times (cos 20 deg x hands off centreline + sin 20 deg x hands above the water), plus the crew's slack line over the crutch. The righting moment is displacement x g x GM x sin(heel).

*Table 2. Heel when the pin breaks at the top of its band.*

| Canoe | Displacement [H1, K1] | GM [H2, K2] | Freeboard [H3, K3] | Gunwale under at [H4, K4] | Heel, kneeling [H5, K5] | Heel, standing [H6, K6] | Pull for 5 deg, kneeling [H7, K7] |
| --- | --- | --- | --- | --- | --- | --- | --- |
| Design canoe | 550 kg | 0.69 m | 461 mm | 40 deg | 3.4 deg | 4.4 deg | 523 N |
| Small dugout | 280 kg | 0.15 m | 299 mm | 39 deg | 23.7 deg | 34.1 deg | 53 N |

The pin protects the design canoe with a margin of 1.5 over the top of its band (kneeling). It does not protect the small dugout: 53 N heels it 5 deg, less than half of what a hooked net needs. A lighter 1.4 mm pin (148 N nominal [O11]) still heels the dugout 12.2 deg [L5]. Amish decided on 2026-10-03 (SMR-DDR-003) to keep the rule: the tool is used only from canoes 7 m or longer with at least three crew. At TRL 4, real canoes are heel-tested by size class and a pin diameter is set for each class; a smaller class is served only once a measured pin suits it. The dugout figures above are the reason for the rule, not a design case.

## 4. Pull needed to free the net

The net lies over the branch with a contact angle theta. To lift it, the ring must overcome the far leg's tension multiplied by the capstan factor e^(mu theta), plus the crew's line: pull = 20 N x e^(mu theta) + 30 N.

*Table 3. Pull to lift the net off the branch.*

| Snag | Friction 0.3 | Friction 0.5 | Against the pin band (256 to 347 N) |
| --- | --- | --- | --- |
| Hooked, half a turn | 81 N [F1] | 126 N [F2] | Frees, margin 2.0 at the bottom of the band [F5] |
| Wrapped once round, one and a half turns | 368 N [F3] | 2,260 N [F4] | Breaks the pin first |

If the crew keeps full tension while the operator lifts, the hooked case rises to 196 N [F6], still inside the band; slackening the line is the operating rule. A wrapped net cannot be lifted straight off. Amish decided (SMR-DDR-003) to add a hook head: the ring is unpinned and the hook head pinned into the same fork with a calibrated pin, and the hook pulls the bight of net back round the branch half a turn at a time; the unwinding technique is taught with the ring and the hook. Each half turn worked back divides the pull by 1.6 to 4.8:

*Table 3a. Pull to lift as a wrapped net is worked back.*

| Turns of net on the branch | Friction 0.3 | Friction 0.5 |
| --- | --- | --- |
| One and a half (wrapped once round) | 368 N [F3] | 2,260 N [F4] |
| One (worked back half a turn) | 162 N [F7] | 493 N [F8] |
| One half (hooked) | 81 N [F1] | 126 N [F2] |

With low friction, one half turn worked back brings the lift inside the pin band; with high friction it takes two. The pull the hook itself needs to drag a bight round depends on how the net lies and cannot be set on paper; it is still limited by the same pin, so the hook cannot heel the canoe more than the ring can. R1 stays at risk until the TRL 4 staged-snag trials, where the hook is tried beside the ring.

## 5. Reach

- Top hand to ring centre: 4.18 m [R1] (three 1.45 m sections, hands 0.3 m below the cap). R2 met.
- Depth reached at 20 deg lean, kneeling: 3.17 m below the surface [R2].
- Tether cord: 10 m, with 2 m kept above the water to the hands: 8 m below the surface [R3]. R2 met.
- Ring inside diameter 100 mm [R4]; the hinged ring opens fully, so any line from 4 to 16 mm goes in. R6 met.

## 6. Strength and stiffness

*Table 4. Strength checks against the top of the pin band (347 N).*

| Check | Result |
| --- | --- |
| Euler buckling of the whole pole, 4.35 m, pinned ends | 767 N [S1]; factor 2.2 [S2] |
| Lock pins, 6 mm stainless, double shear | factor 49 [S3] |
| Pole wall bearing at a lock pin hole | factor 22 [S4] |
| Sleeve rivets, two per sleeve (pull only; push butts the tubes) | factor 17 [S5] |
| Tang tear-out above the shear pin hole | factor 44 [S6] |
| Ring bending, pulled at the tang against the far side | 36 MPa [S7]; factor 6.5 on yield [S8] |
| Tang bending, a quarter of the pull acting sideways | factor 6.5 [S9] |
| Crutch axle, M12, 500 N line tension over the roller | 92 MPa [S10], below the 240 MPa of grade 4.6 |

Everything except the pin is at least twice as strong as the pin, so the pin is always the part that lets go. The buckling factor of 2.2 is the smallest margin; the sleeves stiffen the joints, which the Euler figure ignores. The hook head's flat is the same 6 x 28 section as the tang, with the shear pin hole 10 mm below its top, so its tear-out factor is the same as the tang's [S6]. The bamboo pole is checked in section 10.

## 7. Float

The float winder gives 1.26 kg of net lift [B1]. The ring and the cord weigh 0.60 kg in water [B2], so a dropped ring and cord float with a reserve of 2.1 [B3]. With the jigging weight on, the load is 1.57 kg [B4], more than the float holds: in jigging use the cord's end is tied to a thwart.

## 8. Mass

*Table 5. Masses from the model.*

| Item | Mass |
| --- | --- |
| Rider ring with hinge bolt and gate pin | 0.61 kg [M1] |
| Pole head | 0.56 kg [M2] |
| Pole sections, sleeves, rivets, lock pins, cap | 2.61 kg [M3] |
| Jigging weight | 1.12 kg [M4] |
| Gunwale crutch | 1.38 kg [M5] |
| Tether cord, float winder, spare pins | 0.29 kg [M6] |
| Hook head | 0.21 kg [M10] |
| Working tool (ring, head, pole, pins) | 3.78 kg [M7] |
| Whole kit, including the crutch and jigging weight | 6.78 kg [M8] |
| Carried kit, aluminium prototype | 4.28 kg [M11] |
| Carried kit, bamboo local variant | 3.89 kg [V3] |

Correction in v0.2: v0.1 left out the mass of the lock pins, rivets and the jigging weight's pin (about 0.07 kg), because the script read no volume from parts grouped inside a group. The carried kit Amish decided on as 4.02 kg was therefore 4.08 kg; with the hook head it is 4.28 kg.

The longest packed piece is a section with its sleeve, 1.55 m [M9]; packed length meets R7. As Amish decided (SMR-DDR-003), the crutch stays clamped on the canoe as a fitting and the jigging weight is kept at the landing for deep sets, so R7 is judged on the carried kit. The aluminium prototype carries 4.28 kg [M11], 0.28 kg over the 4 kg target; the bamboo local variant carries 3.89 kg [V3] and meets it. A 32 x 1.6 aluminium tube in place of 32 x 2 would bring the prototype to 3.86 kg [N1] with a buckling factor of 1.84 [N2]; Amish decided on 2026-10-04 (2A, SMR-DDR-004) to keep the 32 x 2 pole: R7 is judged on the bamboo local variant (3.89 kg, met), and the prototype's 4.28 kg is recorded, not a failure of R7.

## 9. Build time and cost

- Workshop time for one kit, one smith: 8.1 h [T1] (estimate, galvanising sent out), including 25 min for the hook head. R9 asks for under one day (8 h): at risk, about 5 min over, which is inside the accuracy of the estimate. The TRL 4 build trial decides.
- Parts cost of one aluminium prototype kit at prototype prices: USD 95.50 [C1], including the hook head (USD 3). The pole, sleeves and rivets are 30 % [C5], galvanising 13 % [C6] and the crutch 13 % [C7].
- Value-engineering target: USD 2,000. Estimated cost of the constructable design: USD 299.50 for the prototype run of three aluminium kits, one bamboo pole set and calibration wire (USD 1,700.50 under the target) [C2 to C4].

## 10. Bamboo local variant

Amish decided (SMR-DDR-003) that a bamboo local variant is built alongside the aluminium prototype, with one crutch and jigging weight shared by five canoes at a landing. The variant shares the ring, pole head, pins, hook head, tether and float with the prototype; only the pole differs (`bom/bom-bamboo-variant.csv`). Three treated culms 36 mm outside, 1,450 mm long, are joined by two steel ferrules 40 x 1.5 x 160 mm fixed to the lower culm with an M5 bolt and epoxy; the next culm slides in and is held by the same 6 mm lock pin. The bottom 120 mm of the lowest culm is dressed to 31.8 mm to fit the pole head; the top culm is cut above a node, so no grip cap is needed.

*Table 6. Bamboo local variant.*

| Item | Result |
| --- | --- |
| Bamboo pole (culms, ferrules, bolts) | 2.18 kg [V1], against 2.57 kg for the aluminium pole it replaces [V2] |
| Carried kit | 3.89 kg [V3]; R7 met |
| Buckling of the pole, pinned ends, E 15 GPa | 518 N [V4]; factor 1.49 over the top of the pin band [V5] |
| Buckling if E is only 10 GPa | factor 1.0 [V6] |
| Culm bend test (accept a culm) | 50 N (5 kg) hung at the middle of a 1.4 m span sags 2.9 mm or less [V10] |
| Saving from sharing the crutch and weight among five canoes | USD 17.60 a kit [V7] |
| Parts cost of one kit, crutch and weight shared | USD 54.90 [V8]; R10 (USD 40) not met |

The bamboo pole is less stiff than the aluminium one. A culm with E below about 15 GPa could bow before the pin breaks when the operator pushes hard; that bends the pole but does not load the canoe more than the pin allows. Culms are therefore chosen by the bend test above. The variant costs USD 54.90 a kit at prototype prices, USD 2 more than the USD 52.90 Amish decided on: the hook head (USD 3) is now in every kit, and the bamboo top node saves the grip cap (USD 1). Local bamboo, steel and galvanising prices near the first fishery, measured at TRL 4, decide how close it comes to USD 40.

## 10. Results against the requirements

*Table 7. Summary.*

| Requirement | Result | Status |
| --- | --- | --- |
| R1 | Hooked nets 81 to 126 N; wrapped nets 368 N to 2.3 kN, falling to 162 to 493 N once the hook has worked them back half a turn | At risk |
| R2 | 4.18 m top hand to ring; tether to 8 m | Met on paper |
| R3 | Design canoe 3.4 to 4.4 deg; canoes under 7 m or with fewer than three crew excluded by rule until per-class pins are set at TRL 4; band depends on calibration | Met on paper where the tool is allowed |
| R4 | Pull capped at 347 N; mesh damage not calculable | Cannot be shown on paper |
| R5 | Release time | Cannot be shown on paper |
| R6 | 100 mm hinged ring | Met on paper |
| R7 | Packed 1.55 m; carried 4.28 kg (aluminium prototype), 3.89 kg (bamboo local variant) | Met, judged on the local variant; the prototype's 4.28 kg is recorded (decision 2A) |
| R8 | Galvanised steel, aluminium, stainless, polymers; treated bamboo in the local variant | Met on paper |
| R9 | 8.1 h | At risk |
| R10 | USD 95.50 (prototype); USD 54.90 (bamboo local variant, crutch and weight shared) | Not met |

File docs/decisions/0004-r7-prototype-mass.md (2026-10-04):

---
doc_id: SMR-DDR-004
title: StumpRider R7 judged on the bamboo local variant
project: StumpRider
doc_type: Design decision record
version: "0.1"
status: Draft
date: '2026-10-04'
author: Amish Chadha
license: CERN-OHL-S-2.0
revisions:
- version: "0.1"
  date: '2026-10-04'
  author: Amish Chadha
  change: Amish's round-3 decision 2A recorded
---

# 0004: R7 judged on the bamboo local variant

- **Date:** 2026-10-04
- **Status:** accepted. Decided by Amish on 2026-10-04: "For round 3, I agree with all your proposed recommendations". For StumpRider this accepts option A of open decision O5 in SMR-DEC-001 (portfolio item 2A).

## Context

The aluminium prototype carries 4.28 kg, 0.28 kg over R7's 4 kg (the 4.02 kg quoted earlier was 4.08 kg once lock pins and rivets were counted, and the hook head adds 0.21 kg). The bamboo local variant carries 3.89 kg.

## Options considered

A: keep the 32 x 2 aluminium pole and judge R7 on the bamboo local variant. B: a 32 x 1.6 aluminium tube (3.86 kg carried, buckling factor 1.84). C: restate R7 to 4.3 kg. Recommendation was A.

## Decision

R7 is judged on the bamboo local variant: 3.89 kg carried, met. The aluminium prototype's 4.28 kg is recorded, not a failure of R7, and is weighed at TRL 4. The pole tube is unchanged.

## Consequences

Requirements text, calculation note wording and registers only. No geometry, bill of materials or cost change. Value-engineering target: USD 2,000. Estimated cost of the constructable design: USD 299.50 (USD 1,700.50 under the target).

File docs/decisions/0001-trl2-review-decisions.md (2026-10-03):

---
doc_id: SMR-DDR-001
title: StumpRider TRL 2 review decisions
project: StumpRider
doc_type: Design decision record
version: "0.1"
status: Draft
date: '2026-10-03'
author: Amish Chadha
license: CERN-OHL-S-2.0
revisions:
- version: "0.1"
  date: '2026-10-03'
  author: Amish Chadha
  change: TRL 2 review decisions D1 to D10, decided under Amish's 2026-10-03 pre-approvals
---

# 0001: TRL 2 review decisions

- **Date:** 2026-10-03
- **Status:** decided. Decided by Amish under his pre-approval of 2026-10-03: "start with the first 14 repos from the list of 29 projects. I pre-approve the batch runs along with any recommendations you come up with. I also accept any cost overruns or variations from the assumed scope cost." and, for this batch, "Proceed with the remaining 15 scaffolds". Requirements that are not met or at risk are not decided here; they are posed to Amish in `docs/REVIEW.md` and SMR-DEC-001.

> **Safety:** D3, D5 and D9 set safety limits and rules. Each takes the conservative option and names the evidence that would relax it. The tool never replaces a life jacket and is never a reason to keep children on boats.

## Context

The scaffold (SMR-PRC-001 v0.1) named seven components and left their form, the pin rating, the canoe it is sized for and the way it is handed out open. These had to be settled to write a measurable precis, a massing model and the calculations.

## Options considered and decisions

*Table 1. TRL 2 decisions.*

| # | Question | Options considered | Decision | Why |
| --- | --- | --- | --- | --- |
| D1 | Form of the rider ring | Spring snap clip; open C ring with a pin across the gap; two hinged halves with a pinned gate | Two half rings of 12 mm steel bar, 100 mm inside, hinged on an M8 bolt and closed by an 8 mm clevis pin with a lanyard | Nothing to corrode shut; opens wide for 4 to 16 mm lines; a smith can make it |
| D2 | Pole material for the prototype | Bamboo; aluminium tube; steel tube | Three 1.45 m sections of 6063-T6 aluminium tube 32 x 2 mm, sleeve joints with lock pins | Uniform stiffness, so trials measure the tool; bamboo stays an option in the R7 and R10 decisions |
| D3 | Shear pin and rating | Plastic, brass or soft aluminium pin; one rating or several | One rating: 2.0 mm soft aluminium wire in double shear, 302 N nominal (256 to 347 N); ten pins from every reel broken on CalRig before use | Highest rating that keeps the design canoe under 5 deg of heel at the top of the band. Conservative; relaxed only by a measured heel test on real canoes |
| D4 | Where the pin sits | Pin for pull only, with a push stop; pin for both | The pin carries both push and pull: the tang stops 45 mm short of the end plate; twisting bears on the fork cheeks | One clear limit in both directions |
| D5 | Operating rules | Free use; rules printed on the tool | Operator kneels; crew slackens the line when the operator lifts; every person in a life jacket; tether end tied to a thwart; cut the net rather than risk a capsize; interim rule: not used from canoes under 7 m or with fewer than three crew until a heel test | Conservative; the interim rule is relaxed only by a heel test with the rated pin |
| D6 | Snags beyond pole reach | Second, longer pole; weight on the cord; weight pinned to the ring | A 1.1 kg weight pinned to the tang in place of the pole head, worked on a 10 m tether | A loose weight would not move the ring |
| D7 | Recovery and marking | Plain cord; float on the cord | 6 mm braided polyester cord on a closed-cell foam winder that floats the ring and cord, painted orange | A dropped ring is found and recovered |
| D8 | Net line over the side | Bare gunwale; carved crutch; clamp-on roller | Clamp-on steel saddle with an HDPE roller, for gunwales 30 to 60 mm thick | No drilling of the canoe; no rope cutting into hands or wood |
| D9 | How the tool is handed out | Sale; free handout; with child-protection work | Only through child-protection partners, with the message that nobody dives; first co-design candidates to approach (none approached): Challenging Heights; a Volta landing-site committee through the Fisheries Commission Volta zone; a Ghanaian university fisheries department for trials | The tool must not be read as making child labour safer |
| D10 | Requirements | Change targets; keep | R1 to R10 kept with their targets; design canoe and hard-case dugout defined as assumptions; status given at TRL 3 | Targets are Amish's; the calculations report against them |

## Consequences

- The constructable design (SMR-DDR-002) builds on D1 to D8.
- R1, R3, R7 and R10 come out not met or at risk on paper; they are posed to Amish with options, not decided here.
- Pitch, problem, patent design-arounds and `budget_usd` are unchanged.

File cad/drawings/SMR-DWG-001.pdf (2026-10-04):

CONCEPT, NOT FOR FABRICATION | StumpRider · github.com/BoujeeEnjinia1701/stumprider

FRONT VIEW
Scale 1:5; looking at the front (along +Y)

TOP VIEW
Scale 1:5; looking down (along -Z)

RIGHT VIEW
Scale 1:5; looking at the right side (along -X)

187

172 472

WHOLE TOOL, ASSEMBLED
Scale 1:40; side elevation looking along +Y, ring on the left 4498

DETAIL B: HOOK HEAD
Scale 1:5; front view (along +Y)

Pins into the pole head's fork in place of the ring, same shear pin

175

MAIN SIZES (MM UNLESS STATED)
Rider ring: 12 bar, 100 inside, 124 outside
Two halves, 2 gap at each joint; hinge M8 (+Y), gate pin 8 (-Y) Tang 6 x 28 x 84 on the fixed half; holes 10.5 (tether),
6.5 (jigging weight) and 2.1 (shear pin), 20, 46, 70 up
Pole head: tube 38 x 3 x 120 on a 6 end plate; fork
cheeks 6 x 30, 8 apart; tang top 45 below the plate Shear pin: 2.0 soft aluminium wire, 30 long, ends bent Pole: three 1,450 sections, 32 x 2 aluminium; sleeves 38 x 2.8 x 200, two rivets below and a 6 pin above
Top hand to ring 4,181; packed 1,550
Pin rating 302 N nominal, 256 to 347 N band
Hook head: 6 x 28 x 60 flat, holes 10.5 and 2.1; 10 bar J,
R30 bend, 50 clear throat (SMR-DWG-111)
Bamboo local variant: 36 culms, ferrules 40 x 1.5 x 160 (DWG-112) Third-angle; ring centre at the origin, pole on +X
REV | DESCRIPTION | DATE | BY
P1 | Preliminary GA for TRL 3 (from cad/src/model.py) | 2026-10-03 | AC
P2 | SMR-DDR-002: design for construction | 2026-10-03 | AC
P3 | SMR-DDR-003: hook head detail; bamboo variant note | 2026-10-03 | AC
STUMPRIDER | github.com/BoujeeEnjinia1701/stumprider

## Canoe-worked gillnet release tool: general arrangement

DRAWING NO.
SMR-DWG-001

REV
P3

SHEET
1 of 1

SIZE

## ANSI B

SCALE
1:5

UNITS
mm
PROJECTION | DATE
2026-10-03

DRAWN
Amish Chadha

MATERIAL / NOTES
Kit per bom/bom.csv. PRELIMINARY, NOT FOR FABRICATION
Licensed CERN-OHL-S-2.0 · Design Molecule Lab · designmolecule.com | Generated from cad/src; do not edit by hand

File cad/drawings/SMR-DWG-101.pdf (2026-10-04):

BUILD PLAN SKETCH, PLAN NOT YET BUILT StumpRider · github.com/BoujeeEnjinia1701/stumprider

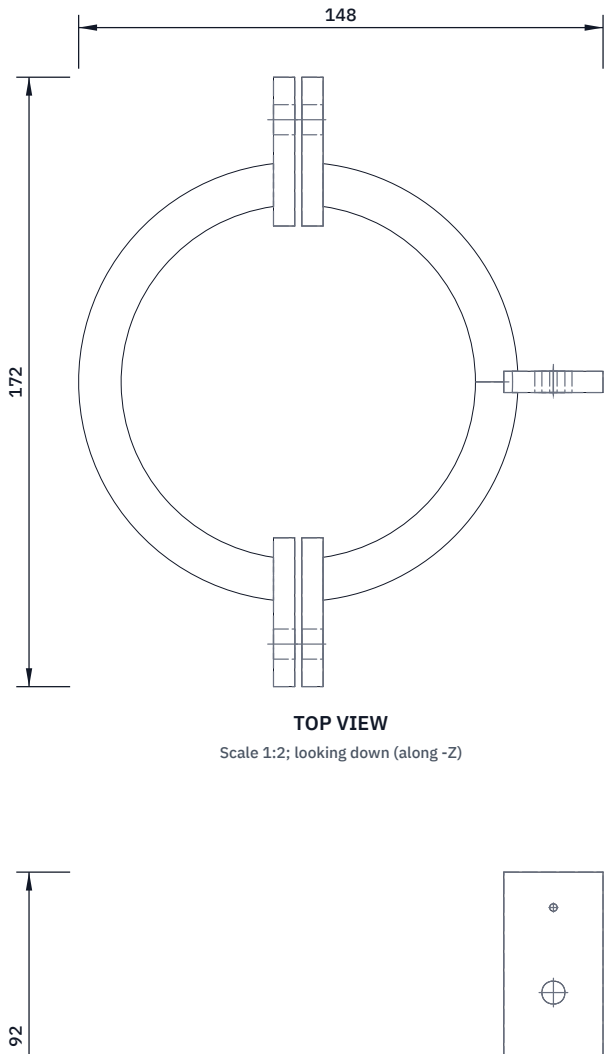
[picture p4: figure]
TOP VIEW; Scale 1:2; looking down (along -Z)

FRONT VIEW
Scale 1:2; looking at the front (along +Y)

RIGHT VIEW
Scale 1:2; looking at the right side (along -X)

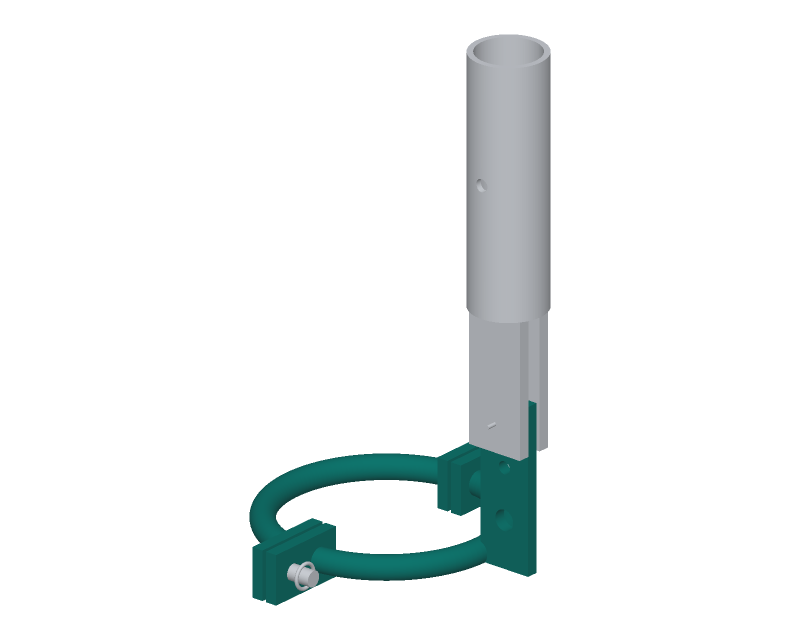
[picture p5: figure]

WHERE IT GOES
This part in colour, its neighbours in grey

HOW TO MAKE IT AND HOW IT FITS
Bend 12 bar round a 100 mm former into a full ring, 112 mean diameter; saw across it to make two halves with a 2 mm gap at each joint.
Ears: four 6 x 25 x 42 flat bar, 8.5 hole 18 out from the bar centre; weld one to each end, holes in line. Tang: 6 x 28 x 84 flat bar, welded on the outside of the fixed half midway between the joints, 4 below its top. Tang holes 10.5, 6.5 and 2.1 at 20, 46 and 70 up,
14 from the inner edge. Galvanise after welding. Check: halves meet with 2 mm gaps, both holes line up.
REV | DESCRIPTION | DATE | BY
P1 | Making sketch for the prototype build plan | 2026-10-03 | AC
STUMPRIDER | github.com/BoujeeEnjinia1701/stumprider

## Rider ring, two halves with ears and tang

DRAWING NO.
SMR-DWG-101

REV
P1

SHEET
1 of 1

SIZE

## ANSI B

SCALE
1:2

UNITS
mm
PROJECTION | DATE
2026-10-03

DRAWN
Amish Chadha

MATERIAL / NOTES
12 mm mild steel round bar; 6 mm flat bar
Licensed CERN-OHL-S-2.0 · Design Molecule Lab · designmolecule.com | Generated from cad/src; do not edit by hand

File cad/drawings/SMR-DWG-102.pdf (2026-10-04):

BUILD PLAN SKETCH, PLAN NOT YET BUILT StumpRider · github.com/BoujeeEnjinia1701/stumprider

FRONT VIEW
Scale 1:2; looking at the front (along +Y)

TOP VIEW
Scale 1:2; looking down (along -Z)

RIGHT VIEW
Scale 1:2; looking at the right side (along -X)

38

38 195

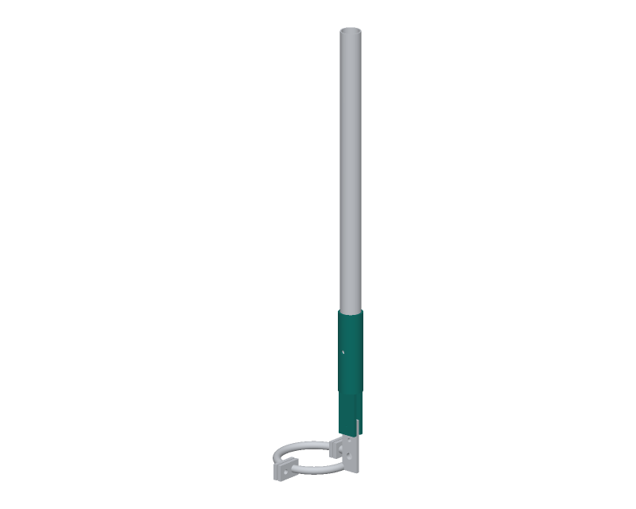
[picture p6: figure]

WHERE IT GOES
This part in colour, its neighbours in grey

HOW TO MAKE IT AND HOW IT FITS
Socket: 38 x 3 steel tube, 120 long, ends square.
End plate: 38 disc of 6 plate, welded across one end. Cheeks: two 6 x 30 x 69 flat bar, welded under the plate, centred, 8 apart inside (use an 8 spacer while welding). Drill the 2.1 shear pin hole through both cheeks together, 55 below the plate.
Drill 6.5 across the socket 60 above the plate. Galvanise; paint the pin rating on the socket. Check: the tang slides between the cheeks freely.
REV | DESCRIPTION | DATE | BY
P1 | Making sketch for the prototype build plan | 2026-10-03 | AC
STUMPRIDER | github.com/BoujeeEnjinia1701/stumprider

## Pole head (socket, end plate and fork)

DRAWING NO.
SMR-DWG-102

REV
P1

SHEET
1 of 1

SIZE

## ANSI B

SCALE
1:2

UNITS
mm
PROJECTION | DATE
2026-10-03

DRAWN
Amish Chadha

MATERIAL / NOTES
38 x 3 steel tube; 6 mm plate and flat bar
Licensed CERN-OHL-S-2.0 · Design Molecule Lab · designmolecule.com | Generated from cad/src; do not edit by hand

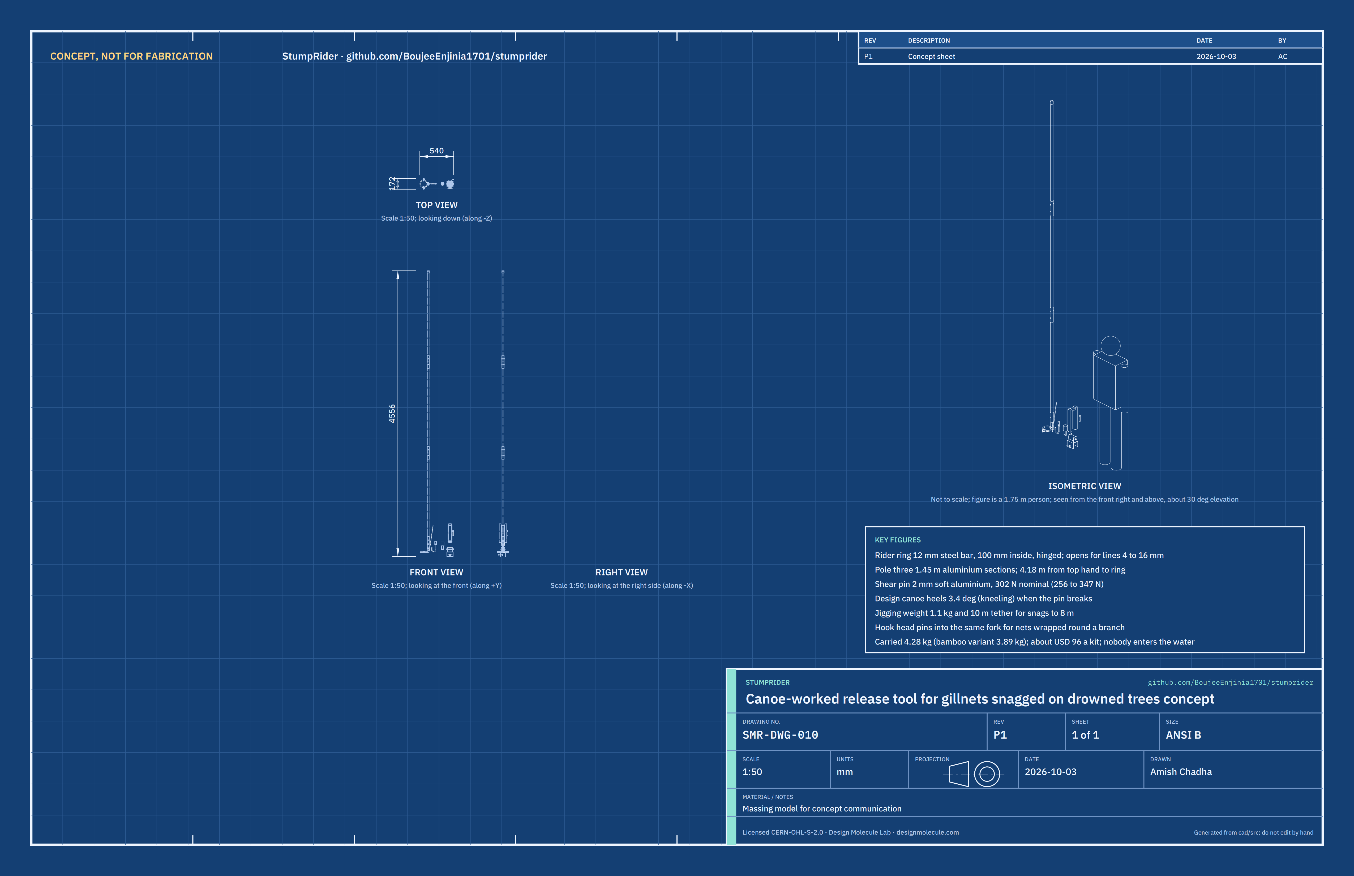
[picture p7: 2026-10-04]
media/concept-blueprint.png

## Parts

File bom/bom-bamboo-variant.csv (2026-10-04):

line | item | qty | spec | supplier | unit_cost_usd | make_buy | notes
V1 | Bamboo culm sections | 3 | Straight seasoned bamboo culm, 36 mm outside (34 to 38 accepted), wall about 6 mm, 1,450 mm long, cut just above a node at the top end; soaked in borax and boric acid solution against rot and insects; ends whipped with galvanised wire; bottom 120 mm of the lowest culm dressed to 31.8 mm to slide into the pole head; 6.5 mm and 5.3 mm cross holes as drawn | Local bamboo seller | 1.00 | Make | SMR-DDR-003. Replaces BOM lines 6 and 10 (the top node closes the culm, so no grip cap). Price basis: culm about USD 0.70 at a riverside market near the first fishery (estimate) and USD 0.30 of borax and boric acid. Mass about 0.57 kg each. Choose culms by a bend test (SMR-DEC-001, to confirm)
V2 | Ferrules | 2 | Steel tube 40 x 1.5 mm (37 mm inside), 160 mm long, deburred; 5.3 mm and 6.5 mm cross holes 40 mm either side of the middle; M5 x 50 stainless bolt with nyloc nut; set on the lower culm with epoxy | Local steel stockist and hardware store | 2.00 | Make | SMR-DDR-003. Replaces BOM lines 7 and 8. Price basis: 160 mm of 40 x 1.5 tube (USD 1.20), M5 bolt and nyloc nut (USD 0.40) and epoxy (USD 0.40). Painted with zinc-rich paint; mass about 0.23 kg each

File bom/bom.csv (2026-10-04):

line | item | qty | spec | supplier | unit_cost_usd | make_buy | notes
1 | Rider ring (two halves with ears and tang) | 1 | 12 mm mild steel round bar, two half rings on a 112 mm mean diameter (100 mm inside), 2 mm gap at each joint; four ears 6 x 25 x 42 mm flat bar with 8.5 mm holes; tang 6 x 28 x 84 mm flat bar on the fixed half with 10.5, 6.5 and 2.1 mm holes; welded, then hot-dip galvanised (line 18) | Local steel stockist | 3.00 | Make | About 0.40 m of bar and 0.25 m of 6 x 30 flat bar. Mass about 0.58 kg
2 | Hinge bolt | 1 | M8 x 30 stainless hex bolt, nyloc nut, two washers | Hardware store | 1.20 | Buy | Permanent hinge between the two ring halves
3 | Gate pin | 1 | 8 x 30 mm stainless clevis pin with an R-clip and a 300 mm lanyard of 3 mm cord tied through the R-clip and the ear | Hardware store | 2.50 | Buy | The only part removed to open the ring; the lanyard keeps it from being lost
4 | Pole head | 1 | 38 x 3 mm steel tube 120 mm long; 38 mm disc of 6 mm plate welded across one end; two fork cheeks 6 x 30 x 69 mm flat bar welded under the disc 8 mm apart, 2.1 mm shear pin hole; 6.5 mm lock pin hole through the tube; hot-dip galvanised (line 18) | Local steel stockist | 3.50 | Make | Mass about 0.56 kg
5 | Shear pins | 12 | 2.0 mm soft aluminium wire (1050 or 1100 alloy, O temper), cut 30 mm long; one fitted, eleven spare; all pins from one reel, which is calibrated before use | Electrical or welding supplier | 0.25 | Make | 1 m of wire makes 30 pins (USD 3 a metre). Rated 300 N in double shear (calculated), to be confirmed on CalRig
6 | Pole sections | 3 | 6063-T6 aluminium tube 32 x 2 mm, 1,450 mm long, ends deburred; 6.5 mm cross holes for the lock pins and 4.9 mm holes for the rivets as drawn | Aluminium stockist | 8.00 | Make | One 6 m length (about USD 33) makes three sections with 1.65 m over. Mass 0.74 kg each
7 | Joint sleeves | 2 | Aluminium tube 38 mm outside, 32.4 mm inside (for example 38 x 2.8 mm), 200 mm long; slide fit on the pole | Aluminium stockist | 2.00 | Make | If only 38 x 3 mm tube is found, open the bore to a slide fit with a flap wheel or emery cloth on a stick
8 | Pop rivets | 4 | 4.8 mm stainless steel blind rivets, grip range 4 to 6 mm | Hardware store | 0.25 | Buy | Two per sleeve on opposite sides; fix each sleeve to the section below it
9 | Lock pins | 4 | 6 x 50 mm stainless clevis pins with R-clips and short lanyards | Hardware store | 1.25 | Buy | Two pole joints, the pole head, and the jigging weight
10 | Grip cap | 1 | Rubber end cap for 32 mm tube, 30 mm deep | Hardware store | 1.00 | Buy | Stops water entering the pole and gives a grip
11 | Tether cord | 1 | 6 mm braided polyester cord, 10 m, about 600 kg breaking strength; ends heat-sealed | Fishing or marine supplier | 5.00 | Buy | Tied to the ring tang with a bowline; the free end is tied to a thwart while working
12 | Float winder | 1 | 40 mm closed-cell polyethylene foam, 300 x 120 mm with a 30 x 60 mm notch at each end; painted orange | Packaging or net float supplier | 2.50 | Make | Floats the ring and cord if dropped (1.26 kg of lift). Mass about 0.04 kg
13 | Spare pin tube | 1 | Polyethylene vial 14 mm across, 80 mm long, with cap; tied to the winder | Pharmacy or hardware store | 0.80 | Buy | Holds the eleven spare shear pins dry
14 | Jigging weight | 1 | 50 mm mild steel round bar 60 mm long; two fork cheeks 6 x 30 x 66 mm flat bar welded to one end face 8 mm apart, 6.5 mm pin hole; hot-dip galvanised (line 18) | Local steel stockist | 4.00 | Make | Mass about 1.1 kg with its pin. Pinned to the tang with a lock pin (line 9) in place of the pole for snags beyond pole reach
15 | Gunwale crutch frame | 1 | 4 mm steel plate: saddle bent to a U, 100 mm long, 70 mm inside, 70 mm legs; two cheeks 60 x 70 mm welded on the web 84 mm apart with 13 mm axle holes; M10 nut welded over a 11 mm hole in the inboard leg; hot-dip galvanised (line 18) | Local steel stockist | 3.50 | Make | Mass about 0.94 kg with the nut
16 | Crutch roller and axle | 1 | HDPE rod 60 mm diameter cut 80 mm long, bored 13 mm; M12 x 110 galvanised bolt with nyloc nut; two 24 mm washers 2 mm thick between roller and cheeks | Plastics stockist and hardware store | 6.00 | Make | Roller turns freely on the bolt; mass about 0.34 kg
17 | Crutch clamp screw | 1 | M10 galvanised threaded rod 100 mm, 30 mm pad disc of 5 mm plate welded on one end, 8 mm bar T-handle 70 mm welded on the other | Hardware store | 2.50 | Make | Clamps gunwales 30 to 60 mm thick
18 | Hot-dip galvanising | 1 | Ring, pole head, jigging weight, crutch frame and clamp pad; about 2.8 kg of steel at a galvaniser's minimum-lot share | Galvaniser | 12.00 | Buy | Can be shared across a batch; zinc-rich paint is the fallback where no galvaniser is near
19 | Marking paint | 1 | Orange enamel, 100 ml: float winder, pole top 300 mm, and the rating mark on the pole head | Hardware store | 2.00 | Buy | Makes a dropped part easy to see and shows the pin rating
20 | Workshop consumables | 1 | Welding rods, cutting and flap discs, drill bits 2.1, 4.9, 6.5, 8.5, 11 and 13 mm | Hardware store | 6.00 | Buy | Share of consumables for one kit
21 | Hook head | 1 | 6 x 28 mm mild steel flat bar 60 mm long with 10.5 and 2.1 mm holes (as the tang); 10 mm mild steel round bar about 0.22 m, bent into a J with a 30 mm bend radius (50 mm clear throat), welded 10 mm up the flat; hot-dip galvanised with the other steel parts (line 18) | Local steel stockist | 3.00 | Make | SMR-DDR-003. Price basis: about 0.22 m of 10 mm bar and 60 mm of 6 x 30 flat bar from the same offcuts as line 1 (USD 1.00), its share of galvanising for 0.2 kg more steel (USD 1.00) and rods and discs (USD 1.00). Mass about 0.21 kg. Pins into the pole head's fork with a calibrated shear pin from line 5

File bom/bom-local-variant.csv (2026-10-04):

line | item | qty | spec | supplier | unit_cost_usd | make_buy | notes
1 | Rider ring (two halves with ears and tang) | 1 | 12 mm mild steel round bar, two half rings on a 112 mm mean diameter (100 mm inside), 2 mm gap at each joint; four ears 6 x 25 x 42 mm flat bar with 8.5 mm holes; tang 6 x 28 x 84 mm flat bar on the fixed half with 10.5, 6.5 and 2.1 mm holes; welded, then hot-dip galvanised (line 18) | Local steel stockist | 3.00 | Make | About 0.40 m of bar and 0.25 m of 6 x 30 flat bar. Mass about 0.58 kg
2 | Hinge bolt | 1 | M8 x 30 stainless hex bolt, nyloc nut, two washers | Hardware store | 1.20 | Buy | Permanent hinge between the two ring halves
3 | Gate pin | 1 | 8 x 30 mm stainless clevis pin with an R-clip and a 300 mm lanyard of 3 mm cord tied through the R-clip and the ear | Hardware store | 2.50 | Buy | The only part removed to open the ring; the lanyard keeps it from being lost
4 | Pole head | 1 | 38 x 3 mm steel tube 120 mm long; 38 mm disc of 6 mm plate welded across one end; two fork cheeks 6 x 30 x 69 mm flat bar welded under the disc 8 mm apart, 2.1 mm shear pin hole; 6.5 mm lock pin hole through the tube; hot-dip galvanised (line 18) | Local steel stockist | 3.50 | Make | Mass about 0.56 kg
5 | Shear pins | 12 | 2.0 mm soft aluminium wire (1050 or 1100 alloy, O temper), cut 30 mm long; one fitted, eleven spare; all pins from one reel, which is calibrated before use | Electrical or welding supplier | 0.25 | Make | 1 m of wire makes 30 pins (USD 3 a metre). Rated 300 N in double shear (calculated), to be confirmed on CalRig
6 | Bamboo pole sections | 3 | Seasoned bamboo culm about 35 mm outside, 1,450 mm long, cut between nodes so each end is closed by a node; borax-boric soak and oil finish against rot; 6.5 mm cross holes for the lock pins as drawn | Local bamboo cutter | 1.00 | Make | Local production variant (SMR-DDR-003, D-A4 C); about 0.55 kg each (0.38 kg/m, estimate); stiffness varies culm to culm and is checked at TRL 4
7 | Steel ferrules | 2 | Mild steel tube about 40 mm inside, 200 mm long, sleeved over the joint and pinned; galvanised with line 18 | Local steel stockist | 2.00 | Make | Local production variant; about 0.12 kg each; replace the aluminium sleeves
8 | Pop rivets | 0 | 4.8 mm stainless steel blind rivets, grip range 4 to 6 mm | Hardware store | 0.25 | Buy | Not used in the local production variant: the ferrules are pinned, not riveted
9 | Lock pins | 4 | 6 x 50 mm stainless clevis pins with R-clips and short lanyards | Hardware store | 1.25 | Buy | Two pole joints, the pole head, and the jigging weight
10 | Grip cap | 1 | Rubber end cap for 32 mm tube, 30 mm deep | Hardware store | 1.00 | Buy | Stops water entering the pole and gives a grip
11 | Tether cord | 1 | 6 mm braided polyester cord, 10 m, about 600 kg breaking strength; ends heat-sealed | Fishing or marine supplier | 5.00 | Buy | Tied to the ring tang with a bowline; the free end is tied to a thwart while working
12 | Float winder | 1 | 40 mm closed-cell polyethylene foam, 300 x 120 mm with a 30 x 60 mm notch at each end; painted orange | Packaging or net float supplier | 2.50 | Make | Floats the ring and cord if dropped (1.26 kg of lift). Mass about 0.04 kg
13 | Spare pin tube | 1 | Polyethylene vial 14 mm across, 80 mm long, with cap; tied to the winder | Pharmacy or hardware store | 0.80 | Buy | Holds the eleven spare shear pins dry
14 | Jigging weight | 0.2 | 50 mm mild steel round bar 60 mm long; two fork cheeks 6 x 30 x 66 mm flat bar welded to one end face 8 mm apart, 6.5 mm pin hole; hot-dip galvanised (line 18) | Local steel stockist | 4.00 | Make | Mass about 1.1 kg with its pin. Pinned to the tang with a lock pin (line 9) in place of the pole for snags beyond pole reach. Local production variant: one shared by five canoes at a landing, so one fifth a kit
15 | Gunwale crutch frame | 0.2 | 4 mm steel plate: saddle bent to a U, 100 mm long, 70 mm inside, 70 mm legs; two cheeks 60 x 70 mm welded on the web 84 mm apart with 13 mm axle holes; M10 nut welded over a 11 mm hole in the inboard leg; hot-dip galvanised (line 18) | Local steel stockist | 3.50 | Make | Mass about 0.94 kg with the nut. Local production variant: one shared by five canoes at a landing, so one fifth a kit
16 | Crutch roller and axle | 0.2 | HDPE rod 60 mm diameter cut 80 mm long, bored 13 mm; M12 x 110 galvanised bolt with nyloc nut; two 24 mm washers 2 mm thick between roller and cheeks | Plastics stockist and hardware store | 6.00 | Make | Roller turns freely on the bolt; mass about 0.34 kg. Local production variant: one shared by five canoes at a landing, so one fifth a kit
17 | Crutch clamp screw | 0.2 | M10 galvanised threaded rod 100 mm, 30 mm pad disc of 5 mm plate welded on one end, 8 mm bar T-handle 70 mm welded on the other | Hardware store | 2.50 | Make | Clamps gunwales 30 to 60 mm thick. Local production variant: one shared by five canoes at a landing, so one fifth a kit
18 | Hot-dip galvanising | 1 | Ring, pole head, jigging weight, crutch frame and clamp pad; about 2.8 kg of steel at a galvaniser's minimum-lot share | Galvaniser | 7.20 | Buy | Local production variant: the crutch and weight share of the lot (USD 6.00) is spread over five canoes, USD 4.80 less a kit
19 | Marking paint | 1 | Orange enamel, 100 ml, and black enamel for lettering: float winder, pole top 300 mm, the rating mark and the interim rule on the pole head (ONLY CANOES 7 m OR LONGER WITH 3 CREW) | Hardware store | 2.00 | Buy | Makes a dropped part easy to see, shows the pin rating and prints the interim rule on canoes (SMR-DDR-003, D-A2 A)
20 | Workshop consumables | 1 | Welding rods, cutting and flap discs, drill bits 2.1, 4.9, 6.5, 8.5, 11 and 13 mm | Hardware store | 6.00 | Buy | Share of consumables for one kit
21 | Hook head | 1 | 6 x 28 mm mild steel flat bar 50 mm long, 2.1 mm shear pin hole 10 mm from the top and 10.5 mm tether hole 26 mm below it; 12 mm mild steel round bar about 150 mm, bent to a J of 28 mm radius (44 mm throat) and welded under the flat; hot-dip galvanised with line 18 | Local steel stockist | 3.00 | Make | Mass about 0.19 kg. Pins into the pole-head fork with a shear pin in place of the ring, to pull the bight of a wrapped net back round the branch (SMR-DDR-003, D-A1 B); tried beside the ring in the TRL 4 staged-snag trials

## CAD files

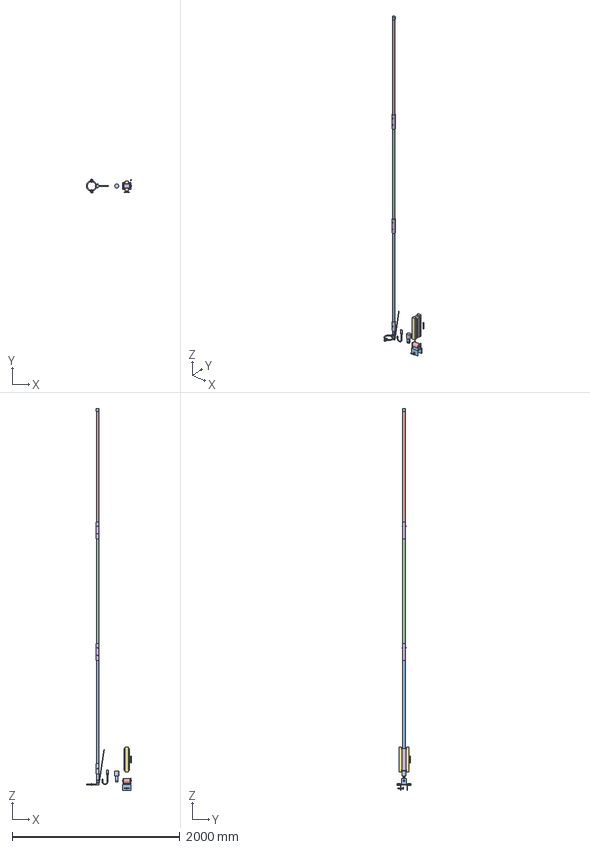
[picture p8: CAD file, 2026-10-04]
cad/step/stumprider-assembly.step
540.0 x 172.0 x 4556.0 mm

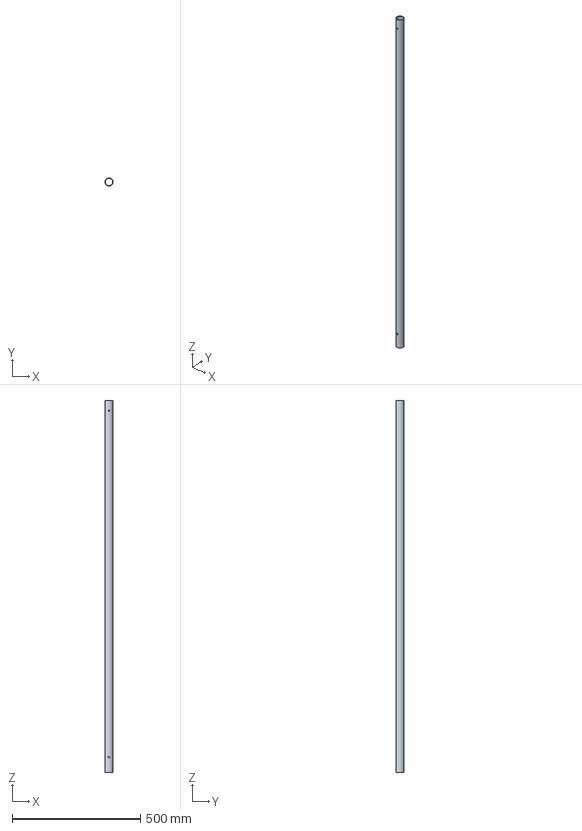
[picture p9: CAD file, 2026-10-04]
cad/step/pole-section.step
32.0 x 32.0 x 1450.0 mm

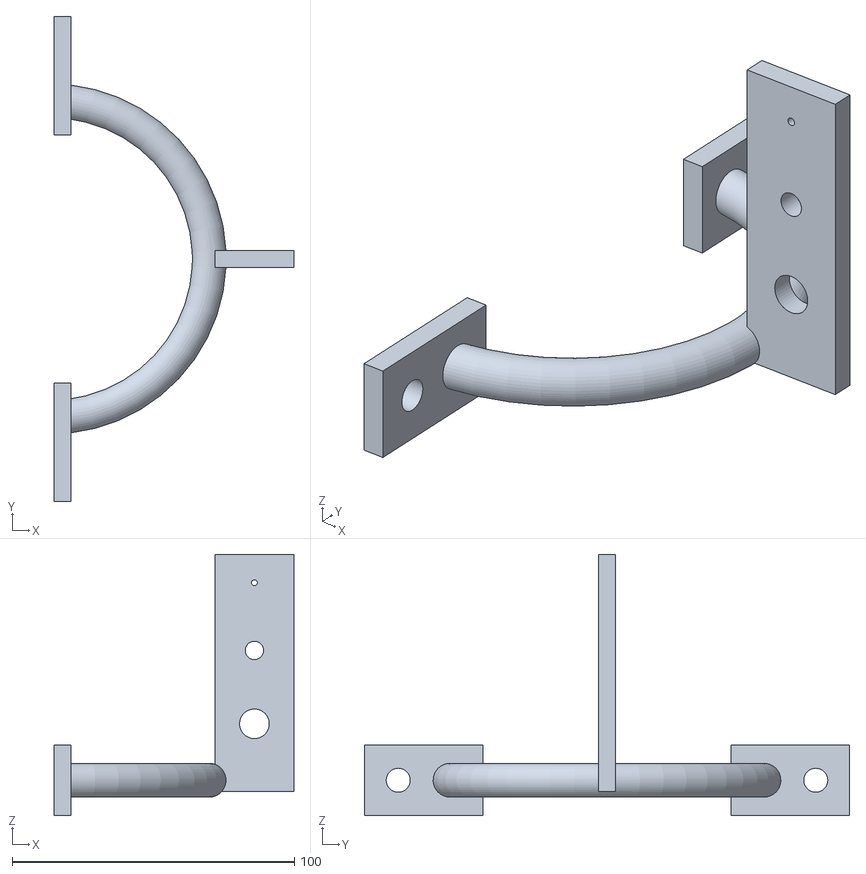
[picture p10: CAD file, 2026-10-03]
cad/stl/ring-fixed-half.stl
85.0 x 172.0 x 92.5

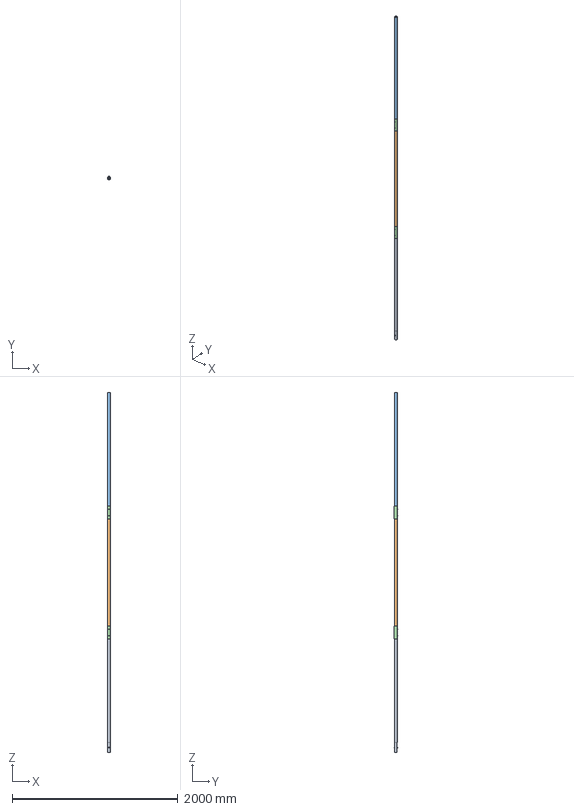
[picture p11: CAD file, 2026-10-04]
cad/step/bamboo-pole-variant.step
40.0 x 52.5 x 4350.0 mm

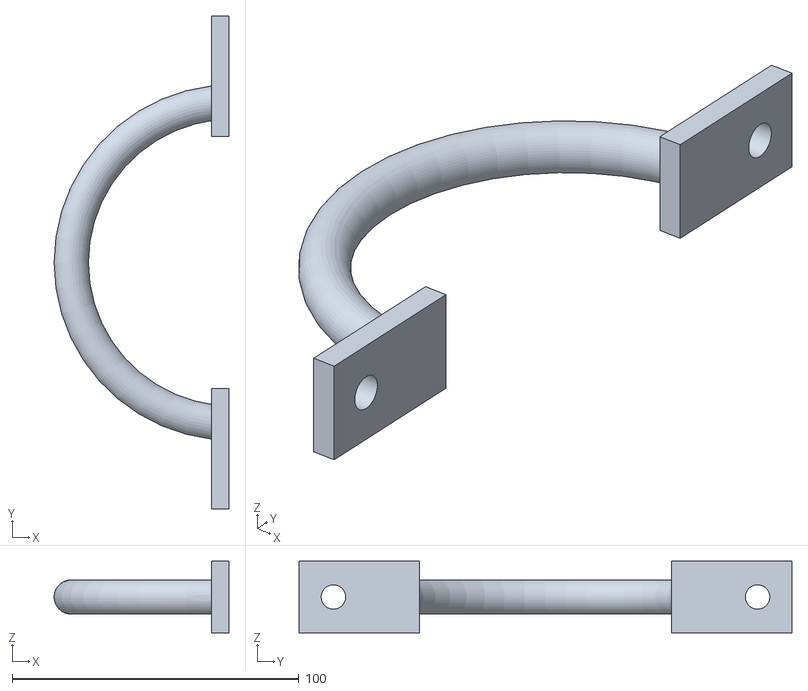
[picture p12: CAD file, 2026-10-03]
cad/stl/ring-swinging-half.stl
61.0 x 172.0 x 25.0

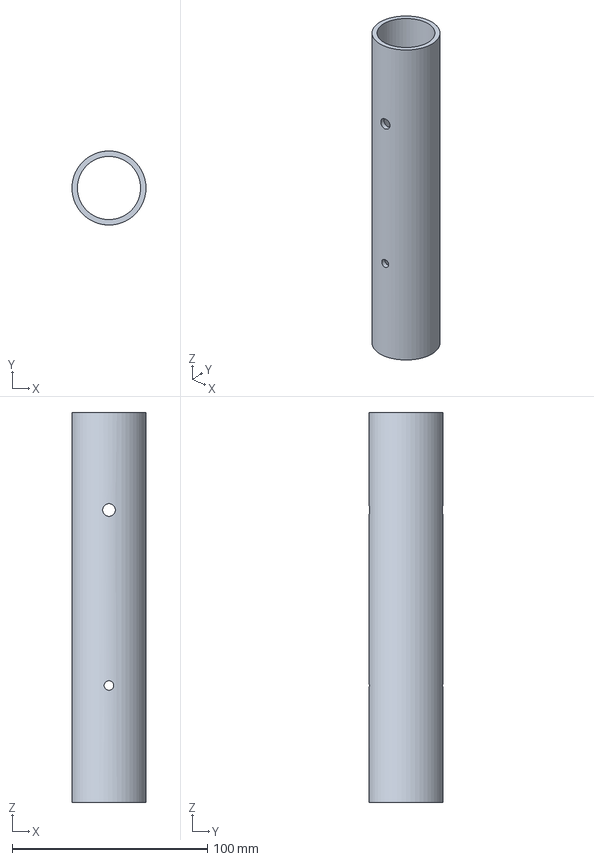
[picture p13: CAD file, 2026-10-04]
cad/step/joint-sleeve.step
38.0 x 38.0 x 200.0 mm

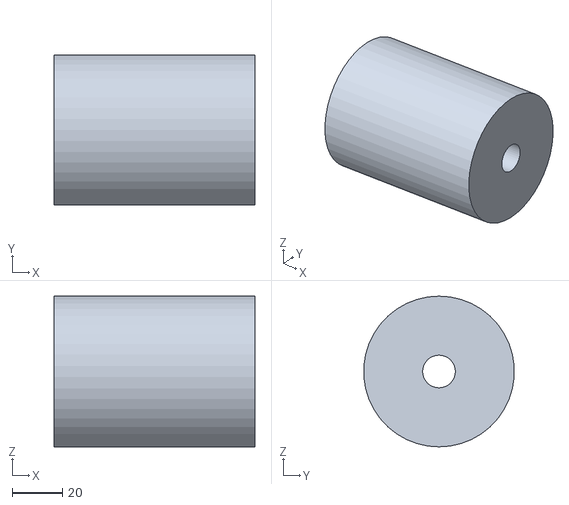
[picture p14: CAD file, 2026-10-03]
cad/stl/crutch-roller.stl
80.0 x 59.8 x 60.0

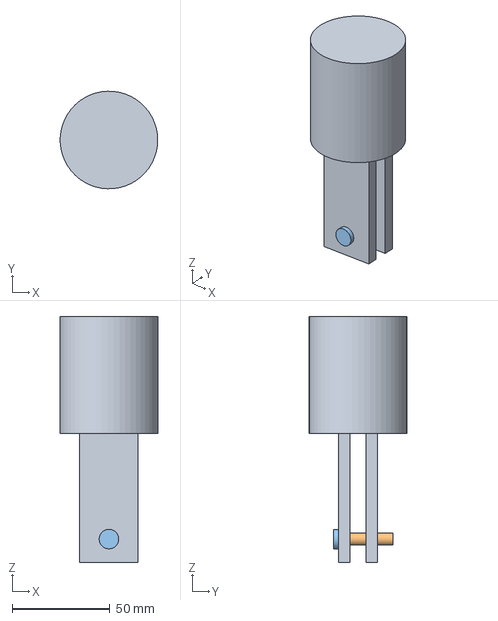
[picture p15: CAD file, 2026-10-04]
cad/step/jigging-weight.step
50.0 x 50.0 x 126.0 mm

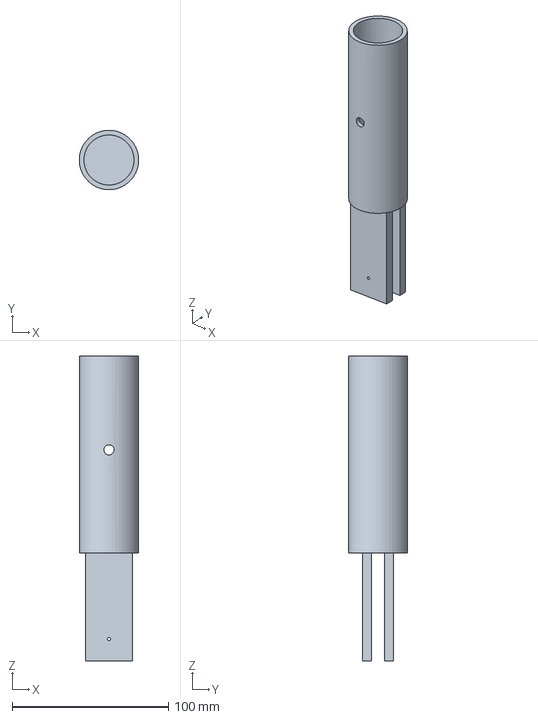
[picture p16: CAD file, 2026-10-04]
cad/step/pole-head.step
38.0 x 38.0 x 195.0 mm

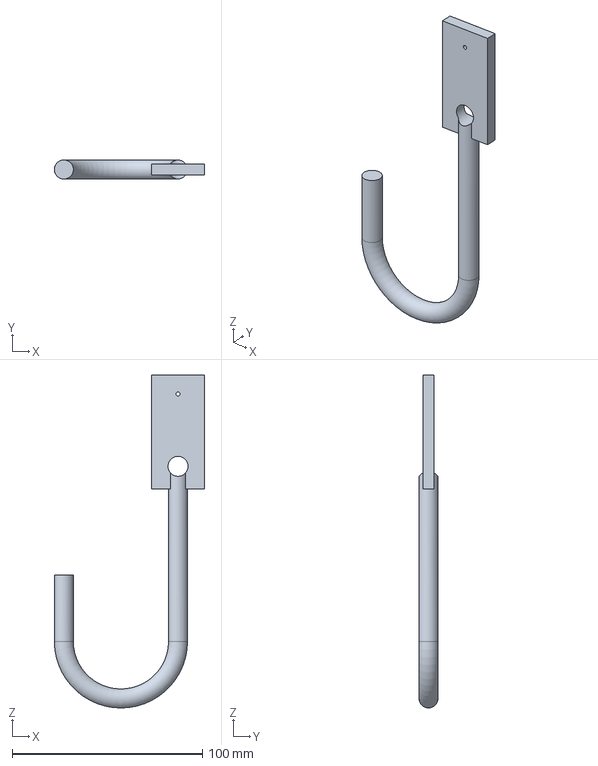
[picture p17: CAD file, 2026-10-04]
cad/step/hook-head.step
79.0 x 10.0 x 175.0 mm

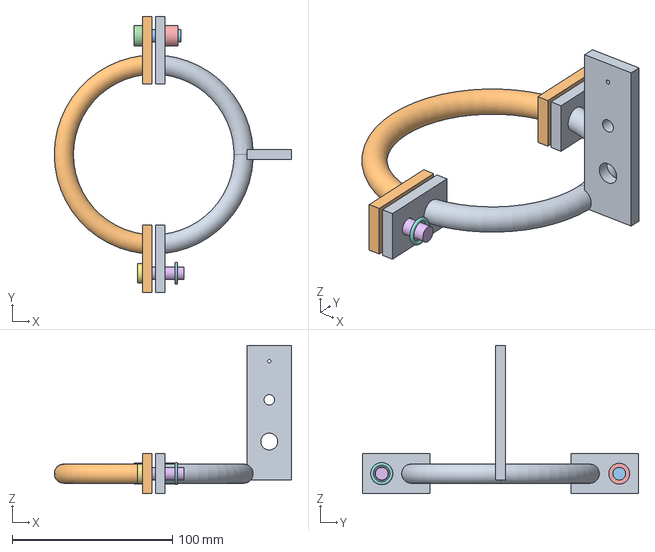
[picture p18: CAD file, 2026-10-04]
cad/step/rider-ring.step
148.0 x 172.0 x 92.5 mm

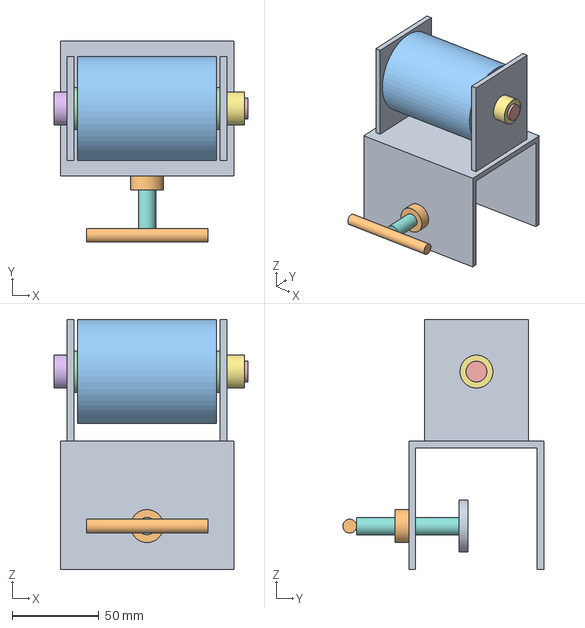
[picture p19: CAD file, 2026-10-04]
cad/step/gunwale-crutch.step
111.5 x 116.0 x 144.0 mm

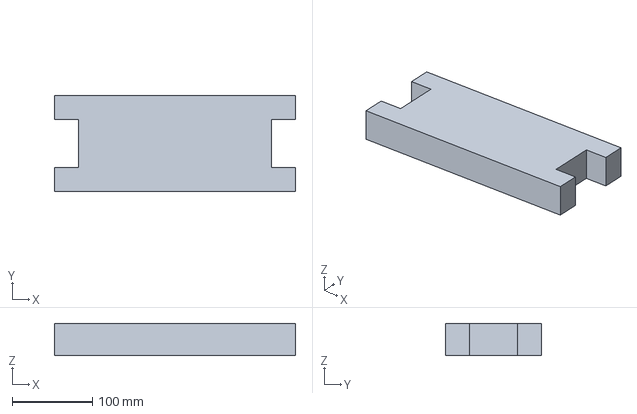
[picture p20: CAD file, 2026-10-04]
cad/step/float-winder.step
300.0 x 120.0 x 40.0 mm

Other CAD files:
cad/stl/float-winder.stl
cad/stl/hook-head.stl
cad/stl/pole-head.stl

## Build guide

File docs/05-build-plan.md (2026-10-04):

---
doc_id: SMR-BLD-001
title: StumpRider prototype build plan
project: StumpRider
doc_type: Build plan
version: "0.2"
status: Draft
date: '2026-10-03'
author: Amish Chadha
license: CERN-OHL-S-2.0
revisions:
- version: "0.1"
  date: '2026-10-03'
  author: Amish Chadha
  change: First build plan; design made constructable (SMR-DDR-002)
- version: "0.2"
  date: '2026-10-03'
  author: Amish Chadha
  change: Amish's decisions of 2026-10-03 (SMR-DDR-003); hook head, bamboo local variant, crutch kept on the canoe and weight at the landing, heel tests by canoe class
---

# StumpRider prototype build plan

**Plan, not yet built.** How to build the first proof-of-concept StumpRider kit, component by component. Building and testing to it is TRL 4 work. Decisions still to be made are kept in the design decisions register (`docs/06-design-decisions.md`), not here.

> **Safety:** StumpRider exists so that nobody enters the water. Nothing in this plan, including the first checks, puts a person in the water. The shear pin is the safety device: fit only pins from a reel that has passed the calibration in section 5, never a nail, bolt or steel wire. On the water, every person wears a life jacket, the operator kneels, and the crew cuts the net rather than risk a capsize. The tool is used only from canoes 7 m or longer with at least three crew; a smaller canoe class is served only once a heel test has set a pin for it. Welding and galvanised steel give off fumes: weld in the open and never weld galvanised parts.

## 1. What you are building

Every component, laid out as packed and numbered in build order

*Figure 1. The kit, numbered in build order.*

The kit is a release tool for a gillnet snagged on a drowned tree. A hinged steel ring closes round the net line and is pushed down onto the snag by a three-piece aluminium pole; the pole holds the ring by a fork and a thin aluminium shear pin that breaks before the pull can heel the canoe too far. A tether on a floating winder brings the ring back, a pinned-on weight works snags too deep for the pole, and a clamp-on crutch with a roller guides the net line over the gunwale. A hook head that fits the same fork pulls a net that has wrapped round a branch back round it. There are 18 components: eleven are made (the ring, pole head, shear pins, pole sections, sleeves, float winder, jigging weight, crutch frame, roller, clamp screw and hook head) and seven are bought (bolts, pins, rivets, cap, cord and a small tube). The steel parts are bent, cut, drilled and welded with a stick welder and then hot-dip galvanised; the aluminium parts are cut and drilled. The parts for one kit cost about USD 96 at prototype prices.

The crutch stays clamped on the canoe as a fitting, and the jigging weight stays at the landing until a deep snag needs it, so the kit carried to and from the canoe weighs about 4.3 kg. A bamboo local variant (section 3.12) uses three treated bamboo culms joined by steel ferrules in place of the aluminium pole; everything else is the same, and one crutch and weight serve five canoes at a landing. It carries about 3.9 kg and its parts cost about USD 55 a kit. One bamboo pole is built alongside the aluminium kits so the two can be compared.

## 2. What changed to make it buildable

*Table 1. Changes from the concept (all recorded in SMR-DDR-002).*

| Component | The concept had | The buildable design has | Why |
| --- | --- | --- | --- |
| Rider ring | A split ring closed by a captive pin | Two half rings with ears at both joints: a bolt hinge on one side, a pinned gate on the other | A ring with a pin across a gap cannot open wide enough to take a line |
| Pole head and ring | A pole head with a shear pin | A steel socket and fork on the pole; a tang welded on the ring; the pin passes through fork and tang; the tang stops 45 mm short of the socket | Push and pull both go through the pin; twisting bears on the fork |
| Pole | Two or three sections | Three 1.45 m sections; riveted sleeves with lock pins | Packs to 1.55 m; joints cannot pull apart |
| Jigging weight | A weight used on the tether cord | A weight that pins to the ring's tang in place of the pole | A weight loose on the cord would not move the ring |
| Gunwale crutch | A roller or crutch | A clamp-on steel saddle with a plastic roller | Fits gunwales 30 to 60 mm thick without drilling the canoe |
| Tether and float | Cord and float | A bowline through the tang; a notched foam winder | A defined tie; the float holds the ring and cord |
| Hook head (SMR-DDR-003) | No tool for a wrapped net | A steel J hook on a flat that pins into the same fork with the same shear pin | A net wrapped round a branch needs more pull than the pin allows until it is worked back |
| Bamboo local variant (SMR-DDR-003) | Aluminium pole only | Three treated bamboo culms with steel ferrules, beside the aluminium prototype | Lighter and cheaper where bamboo grows; one crutch and weight shared by five canoes |

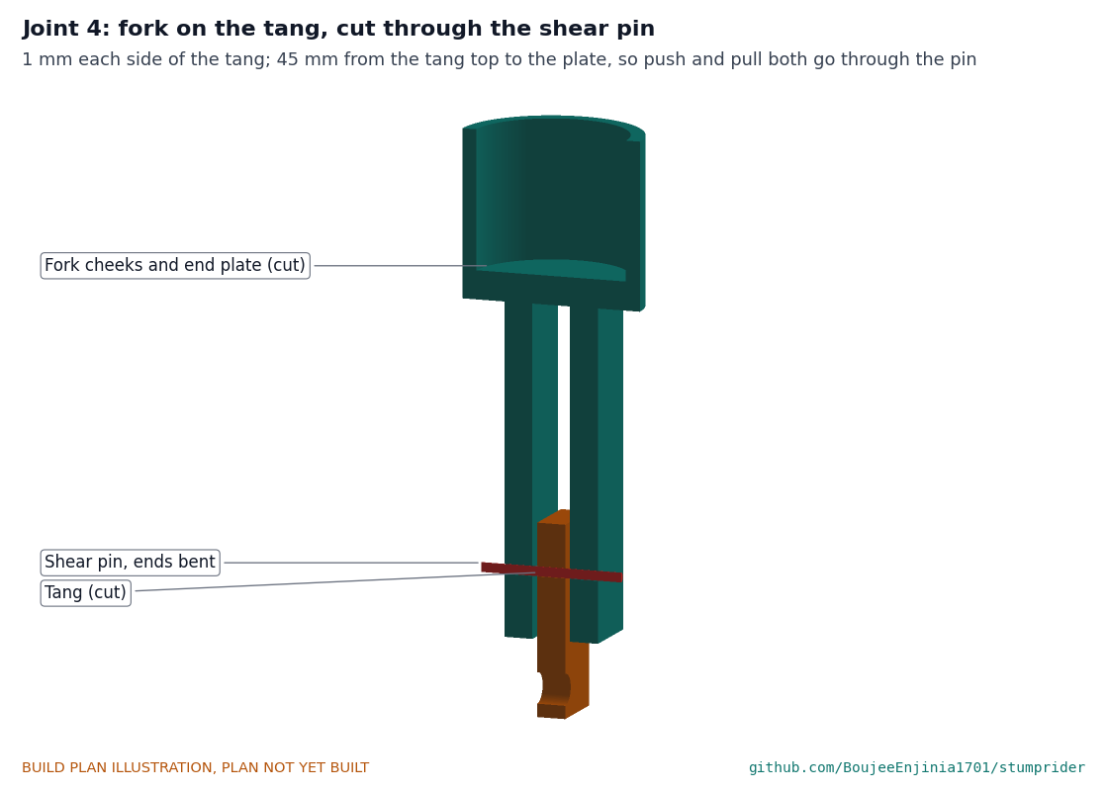
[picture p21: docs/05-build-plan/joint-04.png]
The pole head forked over the ring's tang, cut through the shear pin


*Figure 2. The change that matters most: the shear pin is the only link between the pole and the ring.*

## 3. Making the components

Sizes are in millimetres. Weld only bare steel; galvanise after all welding and drilling of a part is done.

### 3.1 Rider ring (1)

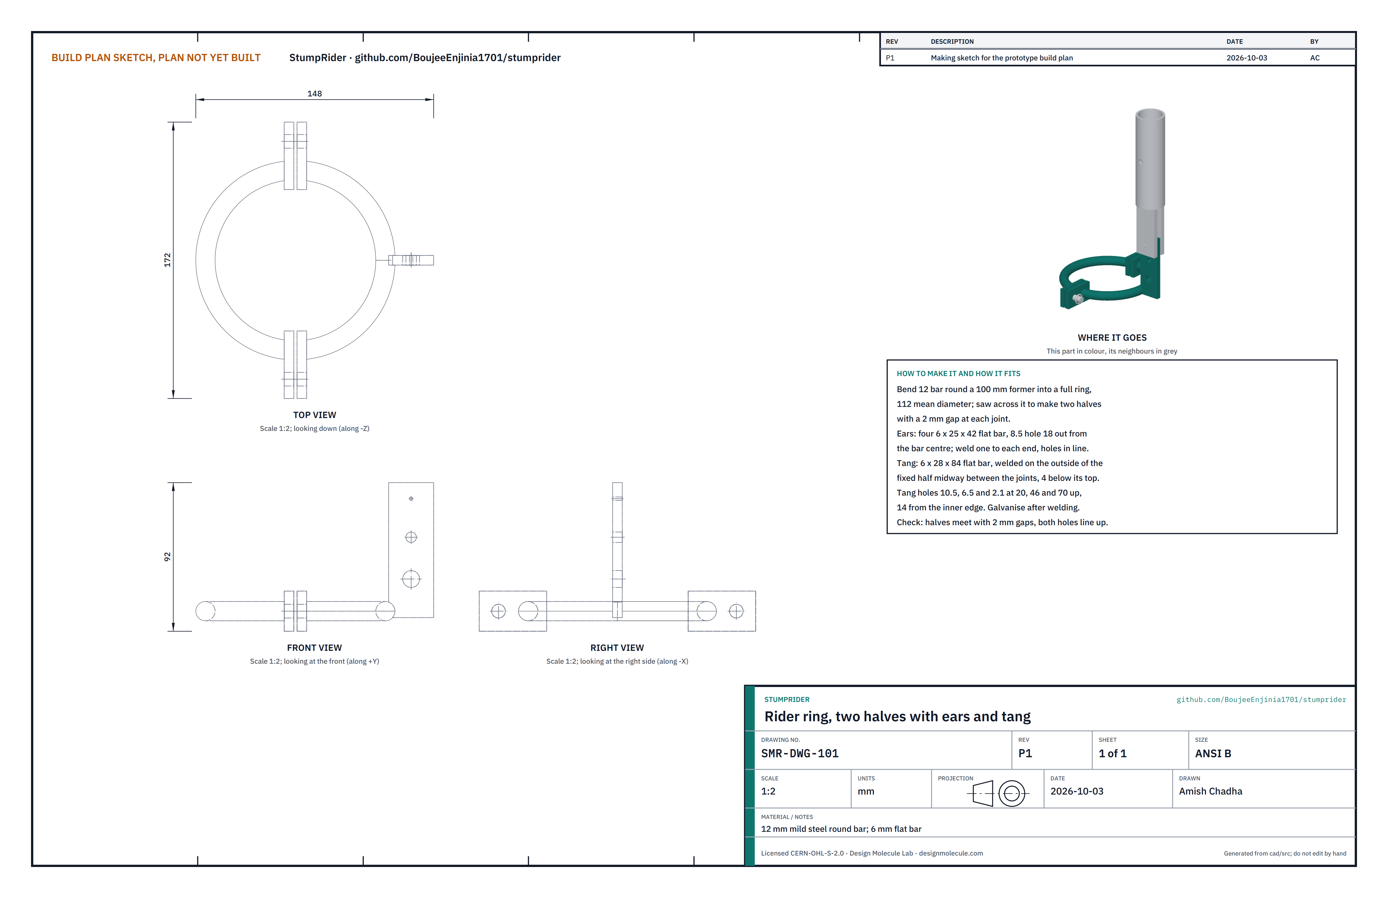
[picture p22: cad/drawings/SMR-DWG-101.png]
Making sketch: rider ring


**What it is and what it is made from.** Two half rings of 12 mm mild steel round bar, 100 inside and 124 outside, each with a flat ear at both ends; a flat tang stands up from the outside of the fixed half. About 0.40 m of bar and 0.25 m of 6 x 30 flat bar.

**How to make it.**

1. Bend 360 of 12 bar round a 100 mm round former (a pipe or a turned block) into a full ring, ends meeting.
2. Mark two points opposite each other and saw across the ring at both, taking out 2 at each cut so the halves meet with a 2 gap.
3. Cut four ears of 6 x 25 flat bar, 42 long. Drill an 8.5 hole in each, 18 out from where the bar centre will sit.
4. Clamp the halves on a flat plate with 2 spacers in the gaps. Weld one ear on the end of each half, faces flat to the joint, so each pair of ears faces the other with a 2 gap and the holes line up.
5. Cut the tang from 6 x 28 flat bar, 84 long. Drill 10.5, 6.5 and 2.1 holes on its centre line at 20, 46 and 70 from the end that will sit lowest.
6. Weld the tang upright on the outside of one half, midway between its ears, with its lower end 4 below the top of the bar and its flat faces square to the ring. This is the fixed half.
7. Grind the welds smooth inside the ring so it slides on a line. Send for galvanising with the other steel parts.

**How it fits the parts next to it.** The ears meet face to face; the hinge bolt goes through one pair and the gate pin through the other.

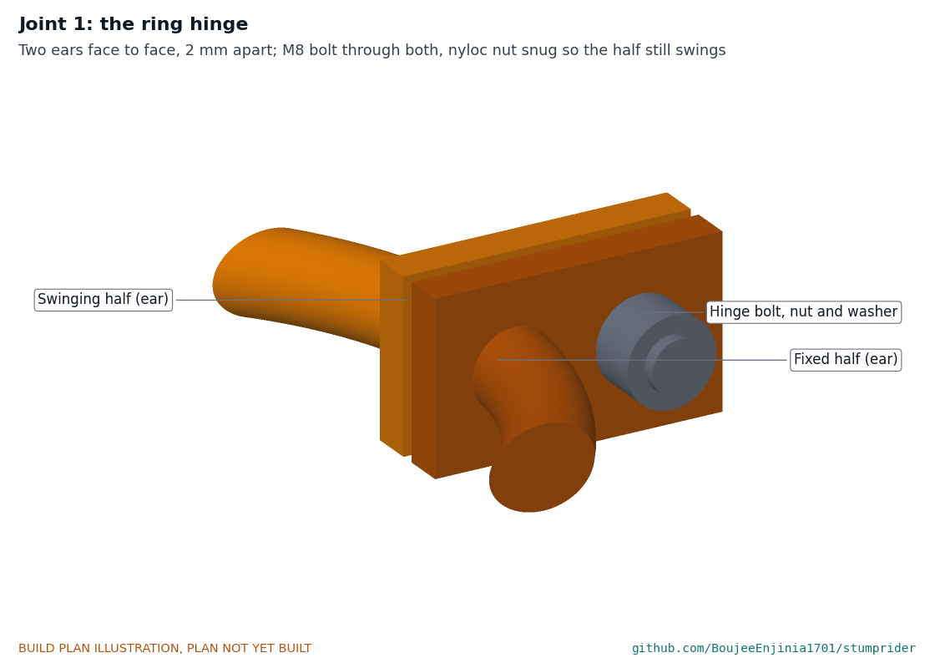
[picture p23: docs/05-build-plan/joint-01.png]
The ring hinge


*Figure 3. The hinge: M8 bolt through both ears, nyloc nut snug.*

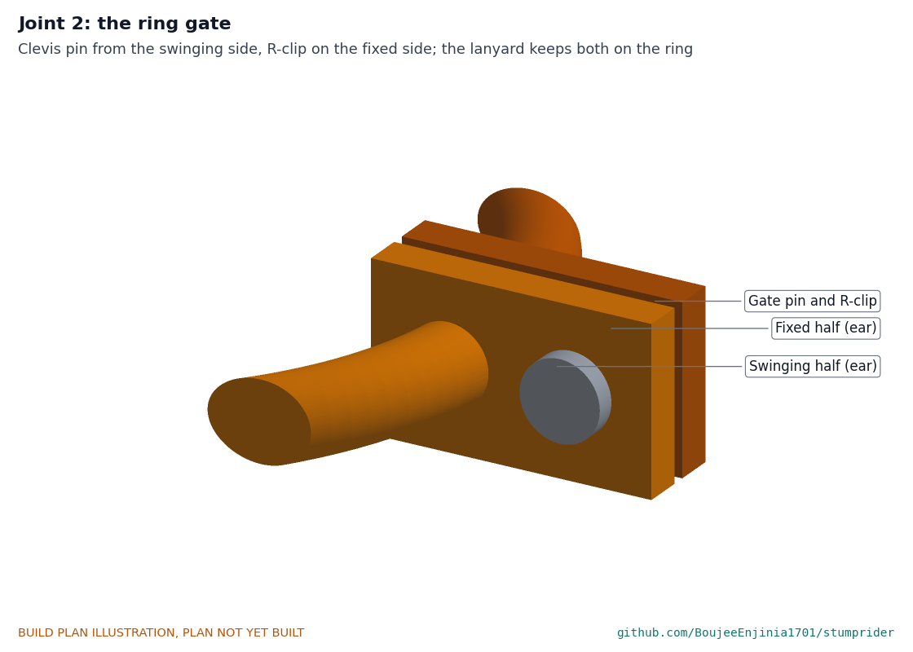
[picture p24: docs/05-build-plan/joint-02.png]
The ring gate


*Figure 4. The gate: clevis pin with R-clip and lanyard.*

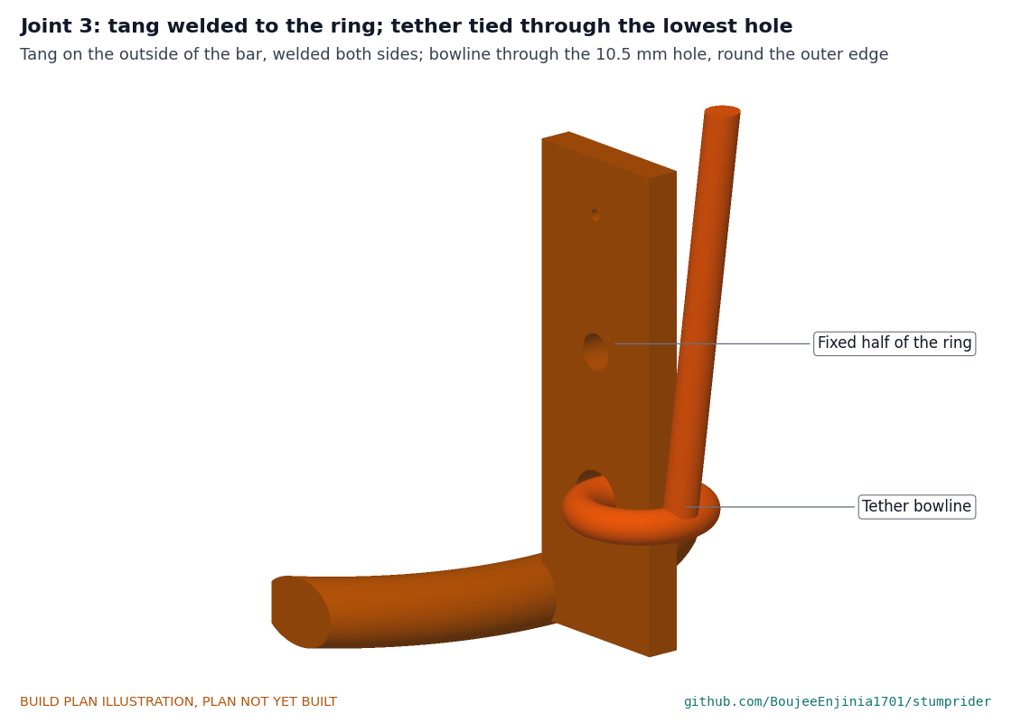
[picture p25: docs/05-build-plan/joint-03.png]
The tang on the ring, with the tether bowline


*Figure 5. The tang, welded on the outside of the bar.*

**Check before moving on.** Both pairs of holes line up with an 8 rod through them; the gaps are 2; the tang stands square; an 8 drill passes the ring's inside without catching on a weld.

### 3.2 Pole head (4)

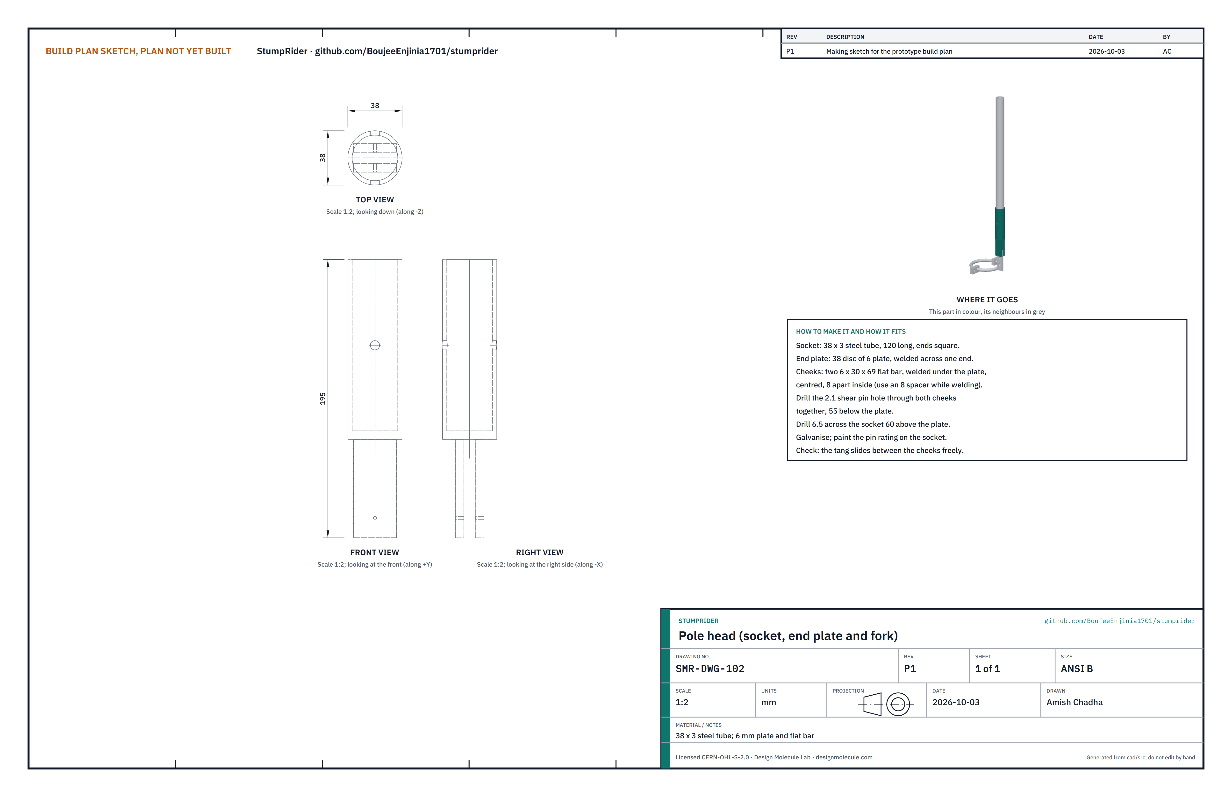
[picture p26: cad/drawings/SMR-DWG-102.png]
Making sketch: pole head


**What it is and what it is made from.** A steel socket that slips over the bottom of the pole, closed by an end plate, with two fork cheeks under it. 38 x 3 steel tube, 6 plate and 6 x 30 flat bar.

**How to make it.**

1. Cut 120 of 38 x 3 tube with square ends; cut a 38 disc from 6 plate.
2. Weld the disc across one end of the tube.
3. Cut two cheeks of 6 x 30 flat bar, 69 long.
4. Hold the cheeks under the disc with an 8 thick spacer between them, centred on the disc and square to it, and weld them to the disc.
5. Clamp the cheeks together on the spacer and drill a 2.1 hole through both, 55 below the disc, on their centre line.
6. Drill a 6.5 hole straight across the tube, 60 above the disc.
7. Galvanise. Paint "302 N PIN ONLY" on the tube.

**How it fits the parts next to it.** The pole goes into the tube until it rests on the disc and is held by a lock pin. The cheeks straddle the ring's tang with 1 clear each side; the tang's top stops 45 below the disc, so it never touches it.

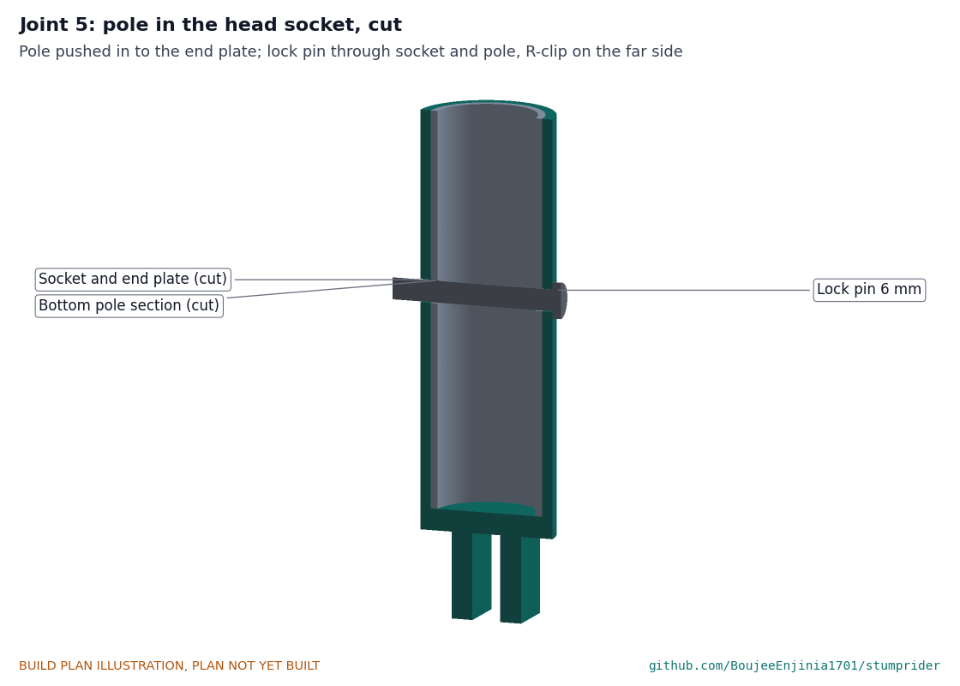
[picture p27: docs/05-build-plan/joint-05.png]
The pole in the head socket, cut


*Figure 6. Pole in the socket, lock pin through both.*

**Check before moving on.** The pole slides in by hand and seats on the disc; the tang slides between the cheeks without binding; a 2 rod passes cheek, tang and cheek holes when lined up.

### 3.3 Shear pins (5)

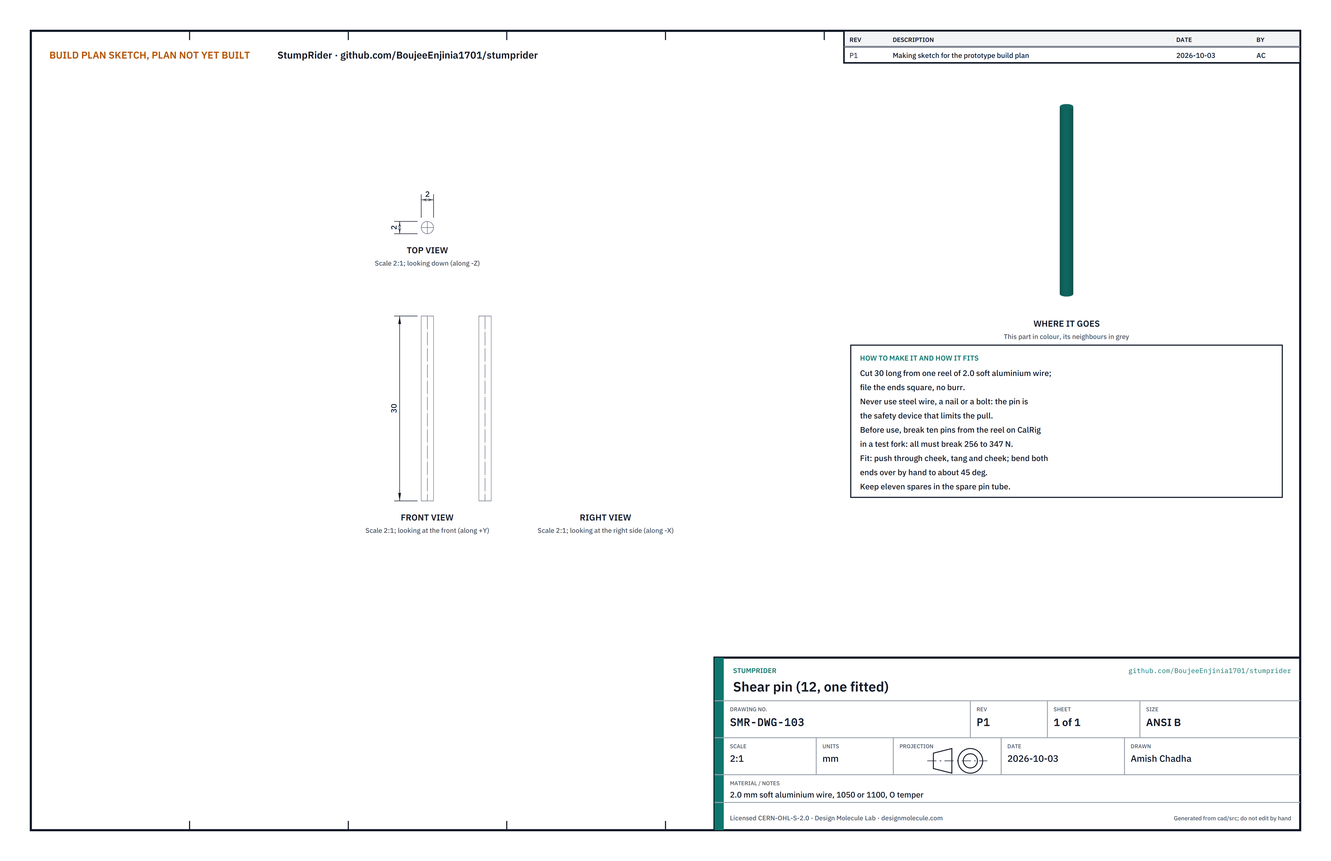
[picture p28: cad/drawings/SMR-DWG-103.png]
Making sketch: shear pin


**What it is and what it is made from.** Short lengths of 2.0 soft aluminium wire (1050 or 1100 alloy, soft temper). They are the safety link: each breaks at about 300 N (30 kg pull).

**How to make it.**

1. Take all pins from one reel of wire and label the reel.
2. Cut twelve pins 30 long; file the ends square, no burr.
3. Calibrate the reel before any pin is used (section 5, check 1).
4. Put eleven in the spare pin tube.

**How it fits the parts next to it.** Pushed through cheek, tang and cheek; both ends bent over by hand to about 45 degrees so it cannot fall out. It is never replaced by a nail, a bolt or steel wire.

**Check before moving on.** The reel has passed calibration; every pin is straight and the same length.

### 3.4 Pole sections (6)

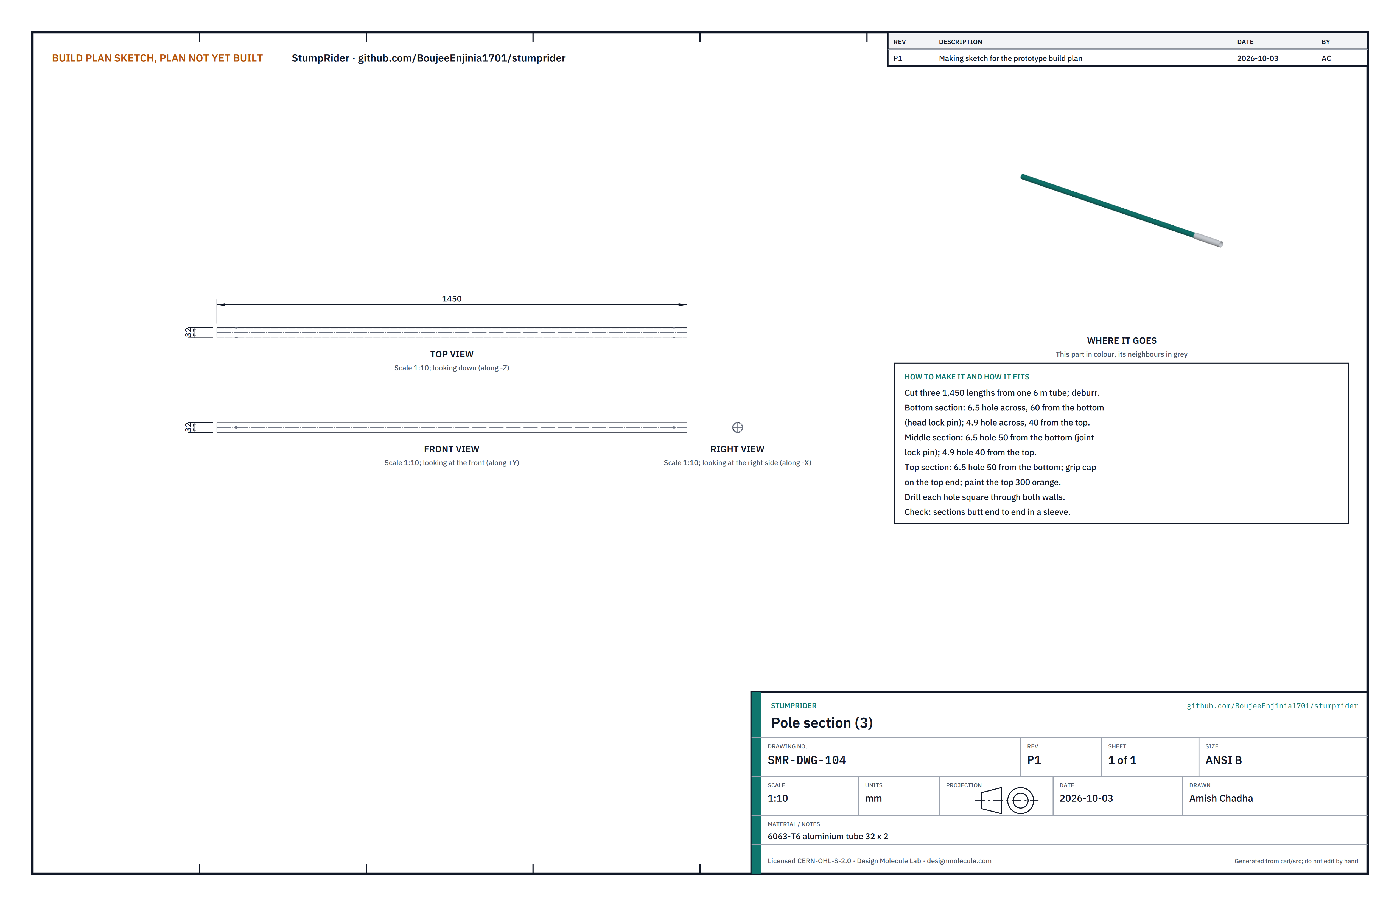
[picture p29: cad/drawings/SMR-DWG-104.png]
Making sketch: pole section


**What it is and what it is made from.** Three 1,450 lengths of 6063-T6 aluminium tube, 32 outside, 2 wall, cut from one 6 m length.

**How to make it.**

1. Cut three 1,450 lengths; deburr inside and out.
2. Bottom section: drill 6.5 straight across, 60 from the bottom end (head lock pin), and 4.9 across, 40 from the top end (rivets).
3. Middle section: 6.5 across, 50 from the bottom end (joint lock pin), and 4.9 across, 40 from the top end.
4. Top section: 6.5 across, 50 from the bottom end. Paint the top 300 orange.
5. Drill every hole square through both walls, with the tube in a vee block.

**How it fits the parts next to it.** The sections butt end to end inside the sleeves (3.5); the grip cap goes on the top of the top section.

**Check before moving on.** All three are the same length within 2; every hole goes straight through.

### 3.5 Joint sleeves (7)

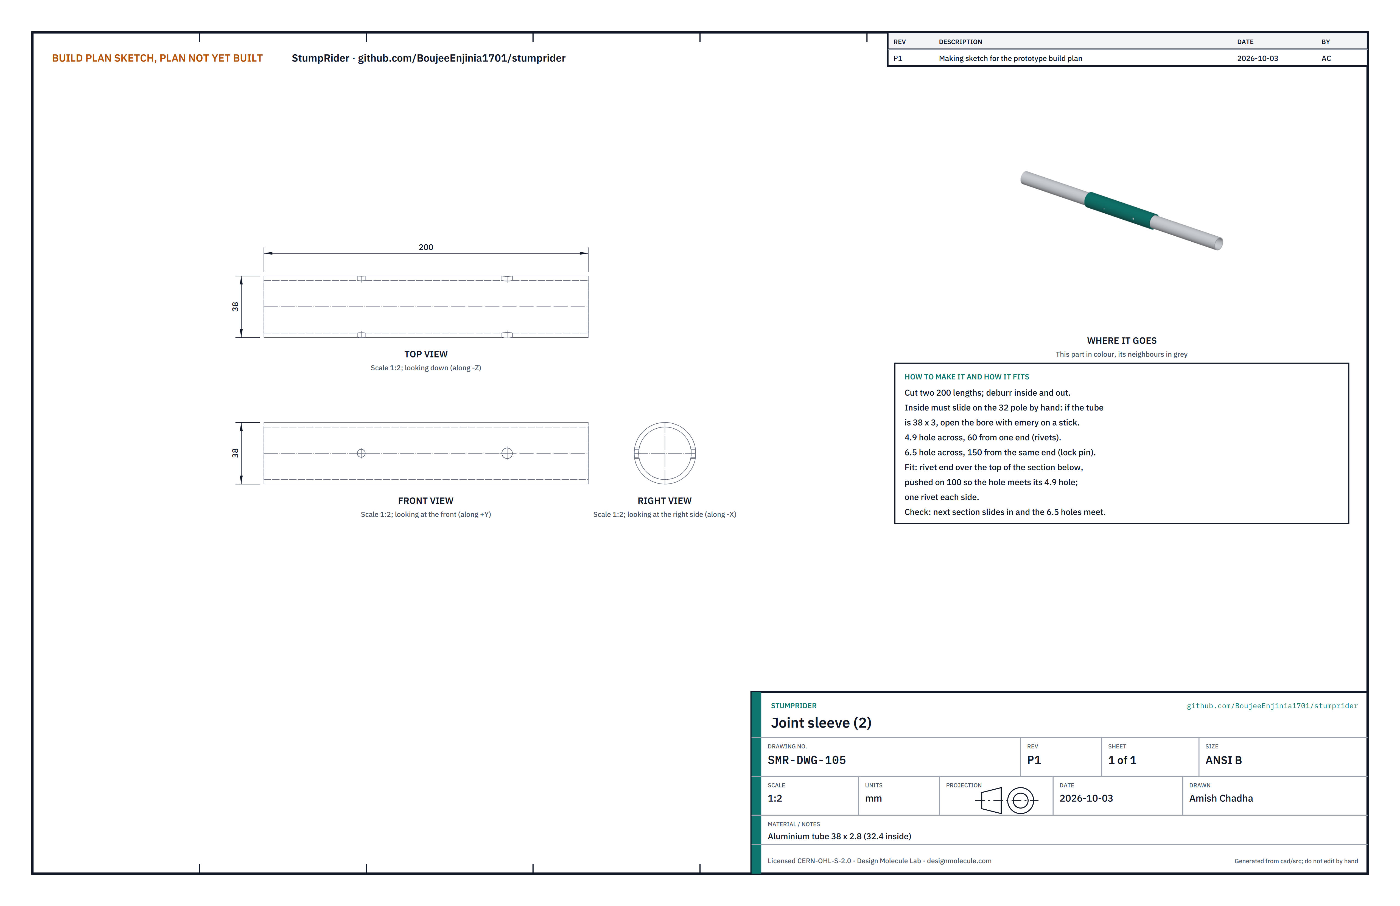
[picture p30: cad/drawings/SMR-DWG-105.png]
Making sketch: joint sleeve


**What it is and what it is made from.** Two 200 lengths of aluminium tube, 38 outside and 32.4 inside, so the pole slides in by hand.

**How to make it.**

1. Cut two 200 lengths; deburr.
2. If the tube is 38 x 3 (32 inside), open the bore with emery cloth on a stick until a pole section slides in by hand.
3. Drill 4.9 across, 60 from one end (rivets), and 6.5 across, 150 from the same end (lock pin).

**How it fits the parts next to it.** The rivet end goes 100 over the top of the bottom (or middle) section and is fixed with two rivets, one each side. The next section slides into the free end until it butts and is held by a lock pin.

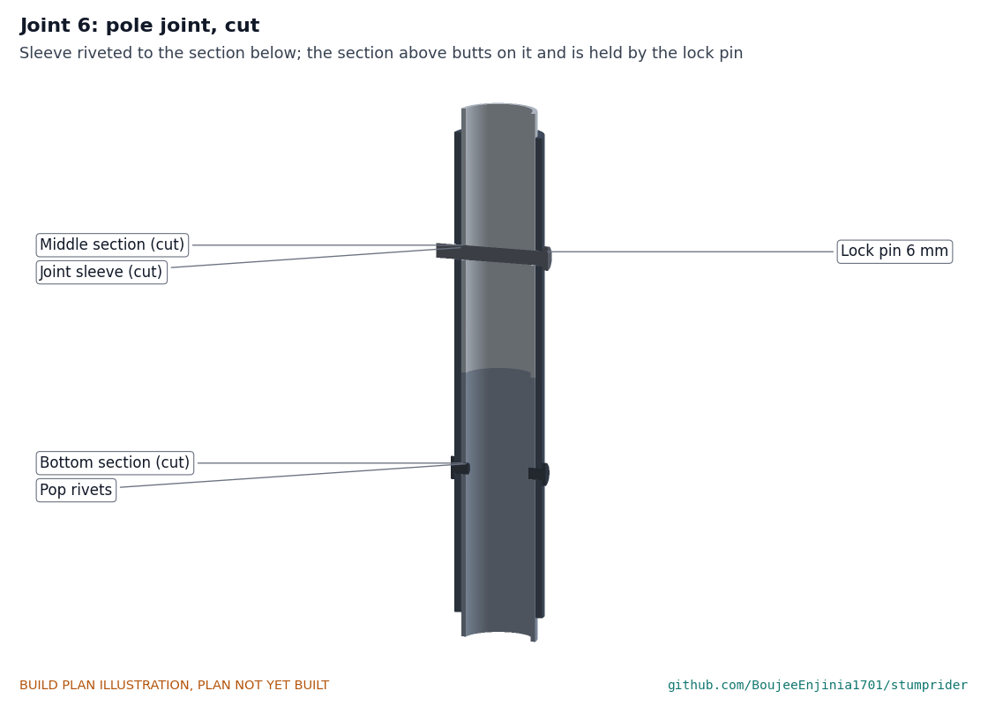
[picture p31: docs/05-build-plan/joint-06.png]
The pole joint, cut


*Figure 7. Pole joint: sleeve riveted below, pinned above.*

**Check before moving on.** The next section slides in and its 6.5 hole lines up with the sleeve's.

### 3.6 Float winder (12)

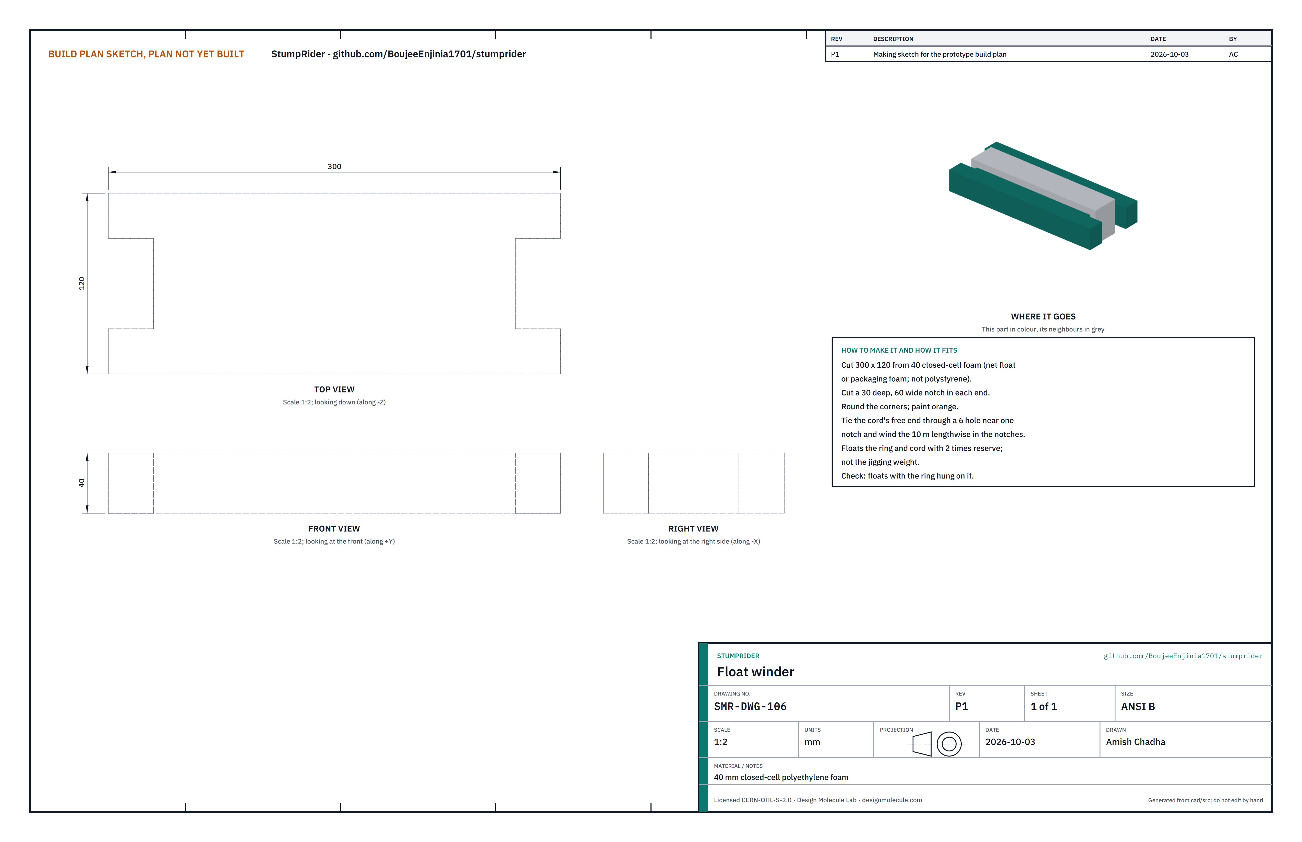
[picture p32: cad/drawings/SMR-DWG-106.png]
Making sketch: float winder


**What it is and what it is made from.** A flat winder for the tether cord, 300 x 120 cut from 40 closed-cell polyethylene foam (net-float or packaging foam, never polystyrene).

**How to make it.**

1. Cut the 300 x 120 blank with a sharp knife.
2. Cut a notch 30 deep and 60 wide in each end.
3. Round the corners; paint orange.
4. Push a 6 hole through near one notch for the cord's end.

**How it fits the parts next to it.** The cord is wound lengthwise through the notches; the spare pin tube is tied to it.

**Check before moving on.** With the ring hung on it in a bucket of water, it floats.

### 3.7 Jigging weight (14)

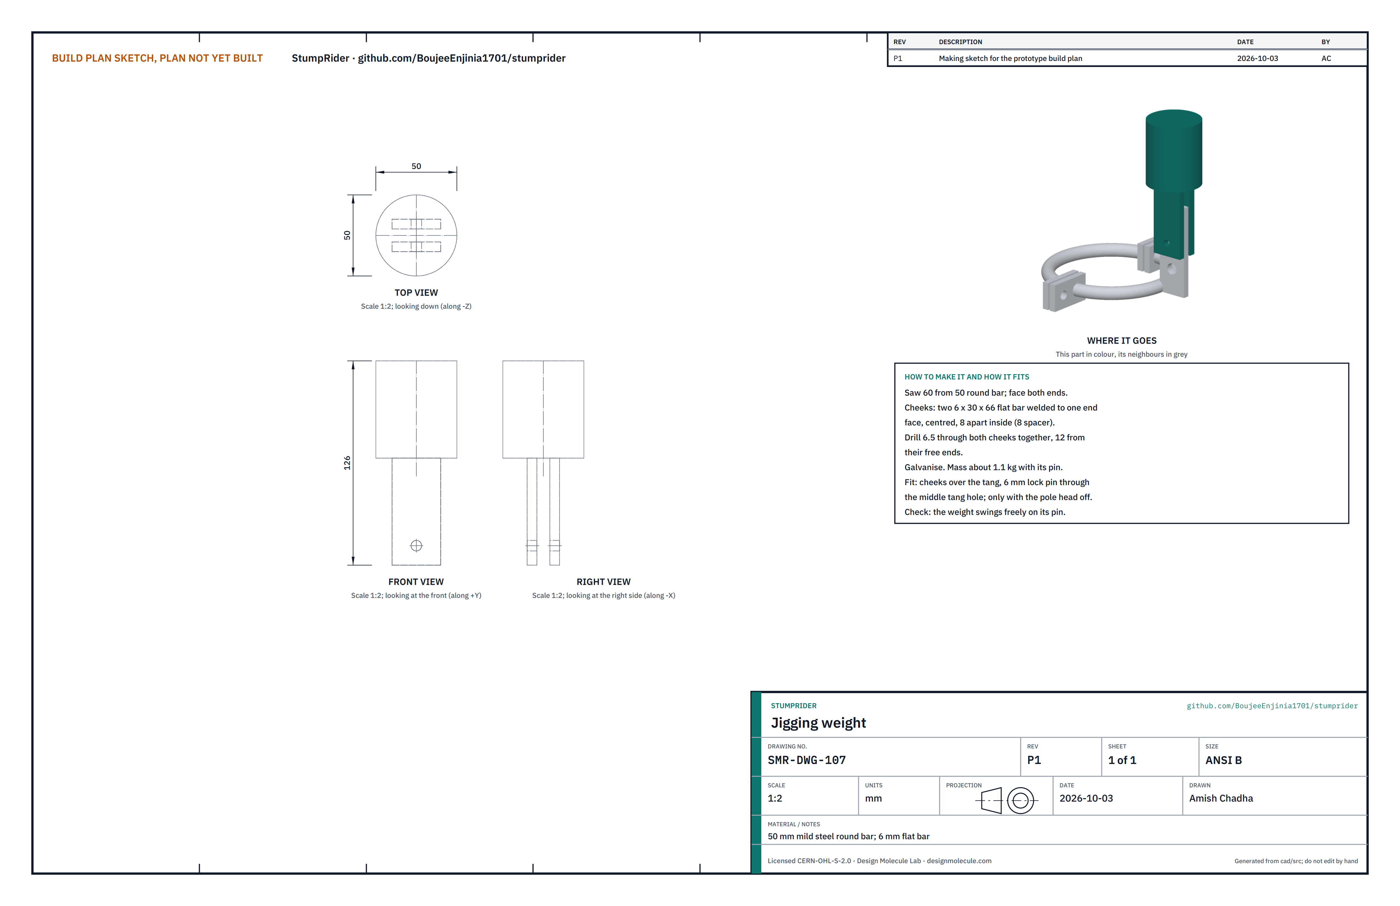
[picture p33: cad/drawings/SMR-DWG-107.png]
Making sketch: jigging weight


**What it is and what it is made from.** A 1.1 kg steel weight with a fork that pins to the ring's tang. 50 round bar and 6 x 30 flat bar.

**How to make it.**

1. Saw 60 from 50 round bar; face both ends flat.
2. Cut two cheeks of 6 x 30 flat bar, 66 long.
3. Weld them to one end face, centred, with an 8 spacer between them.
4. Clamp on the spacer and drill 6.5 through both, 12 from their free ends.
5. Galvanise.

**How it fits the parts next to it.** With the pole head off, the cheeks go over the tang and a lock pin goes through the tang's middle hole.

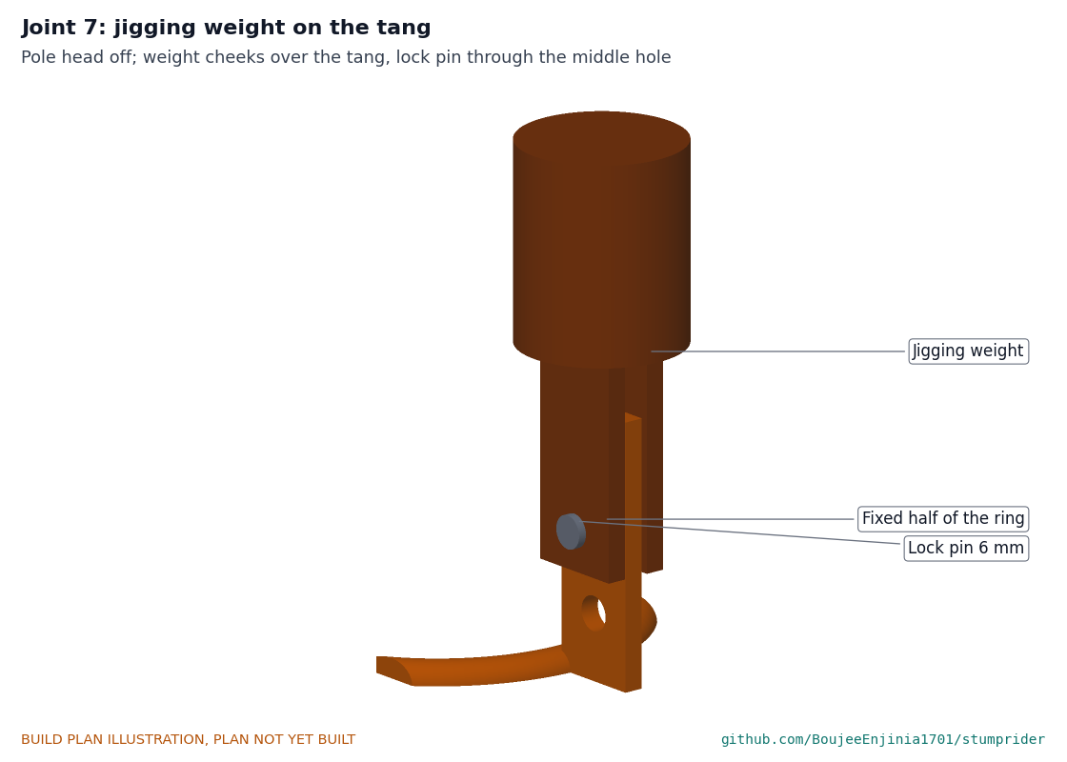
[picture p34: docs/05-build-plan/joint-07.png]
The jigging weight on the tang


*Figure 8. The jigging weight pinned to the tang.*

**Check before moving on.** The weight swings freely on its pin and clears the tether knot.

### 3.8 Gunwale crutch frame (15)

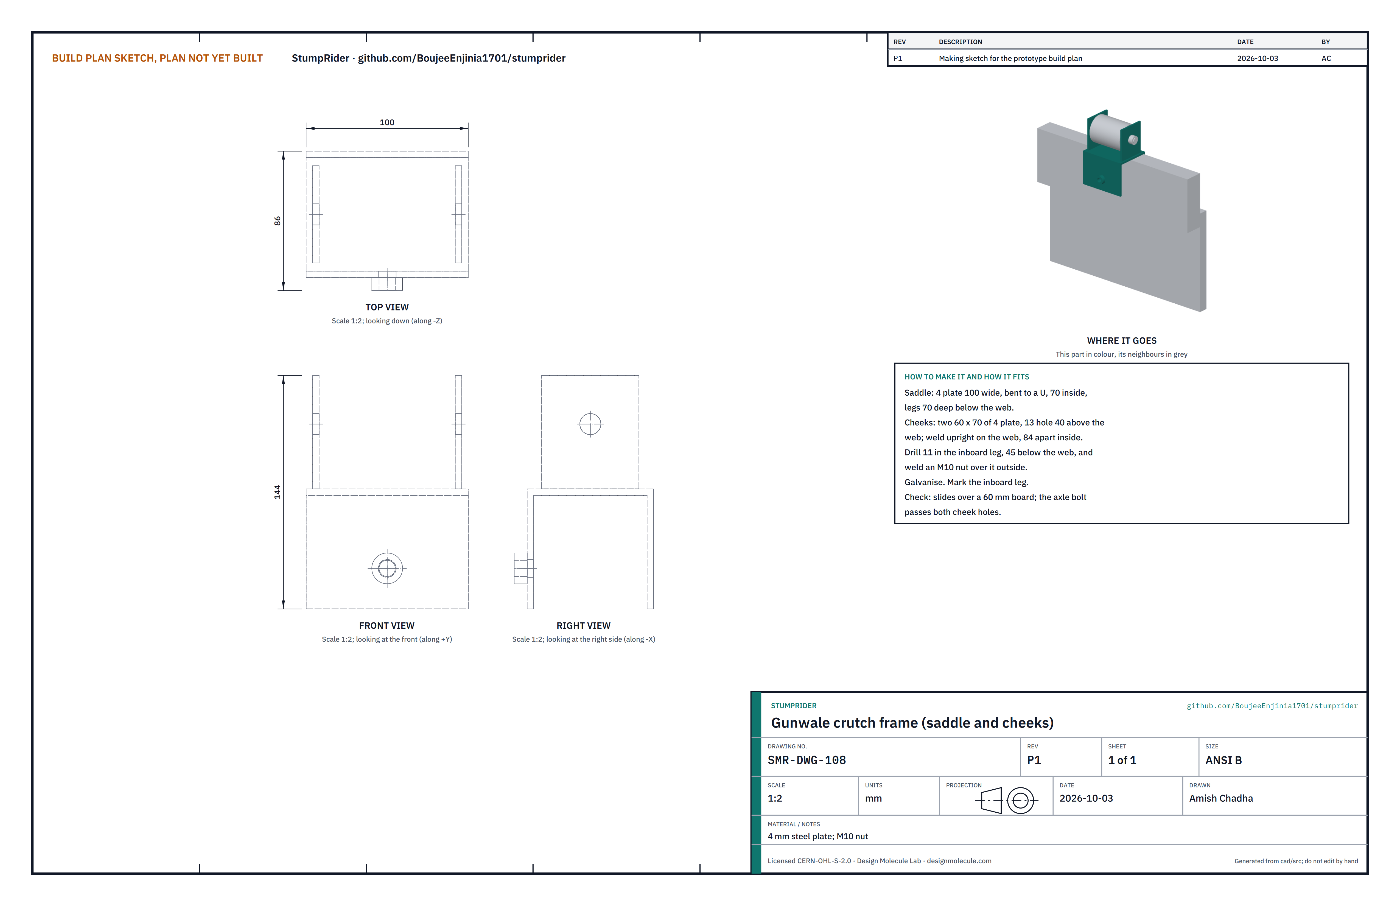
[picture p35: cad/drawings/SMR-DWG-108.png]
Making sketch: crutch frame


**What it is and what it is made from.** A U saddle that sits over the gunwale, with two cheeks that carry the roller. 4 steel plate and an M10 nut.

**How to make it.**

1. Cut a strip of 4 plate 100 wide and 218 long. Bend it to a U, 70 inside, with legs 70 deep below the web.
2. Cut two cheeks 60 x 70 from 4 plate; drill 13 in each, centred across, 40 above where it will sit on the web.
3. Weld the cheeks upright on the web, 84 apart inside, holes in line.
4. Drill 11 in one leg, 45 below the web, centred; weld an M10 nut over it on the outside. This is the inboard leg; mark it.
5. Galvanise.

**How it fits the parts next to it.** The web sits on the top of the gunwale, the outboard leg against the outside of the canoe; the clamp screw's pad bears on the inside face.

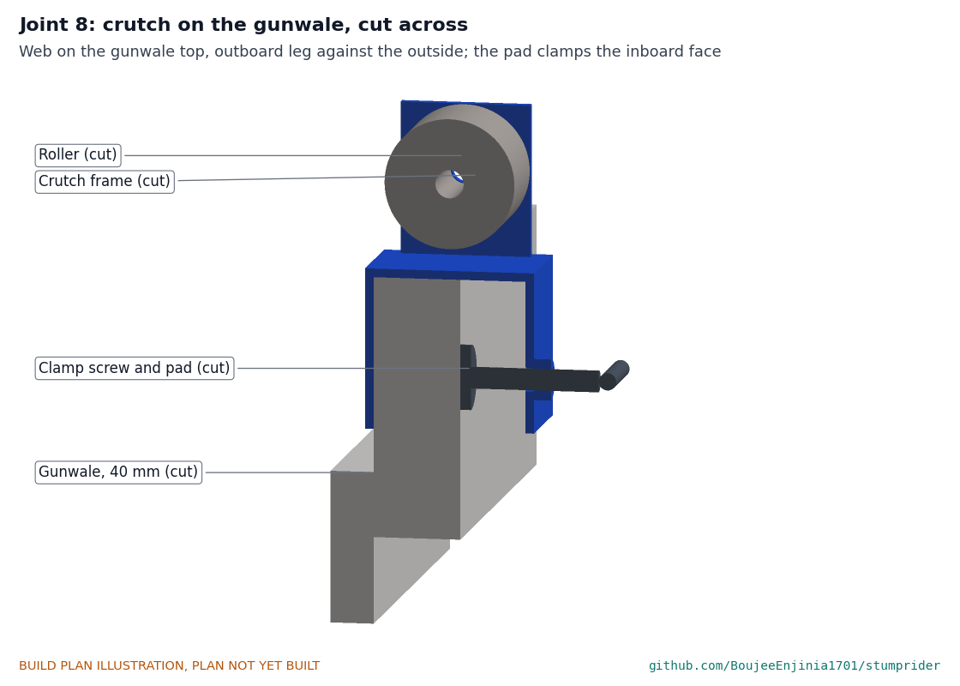
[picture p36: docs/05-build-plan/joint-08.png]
The crutch on the gunwale, cut across


*Figure 9. The crutch on a 40 mm gunwale.*

**Check before moving on.** It slides over a 60 board; an M12 bolt passes both cheek holes.

### 3.9 Crutch roller (16)

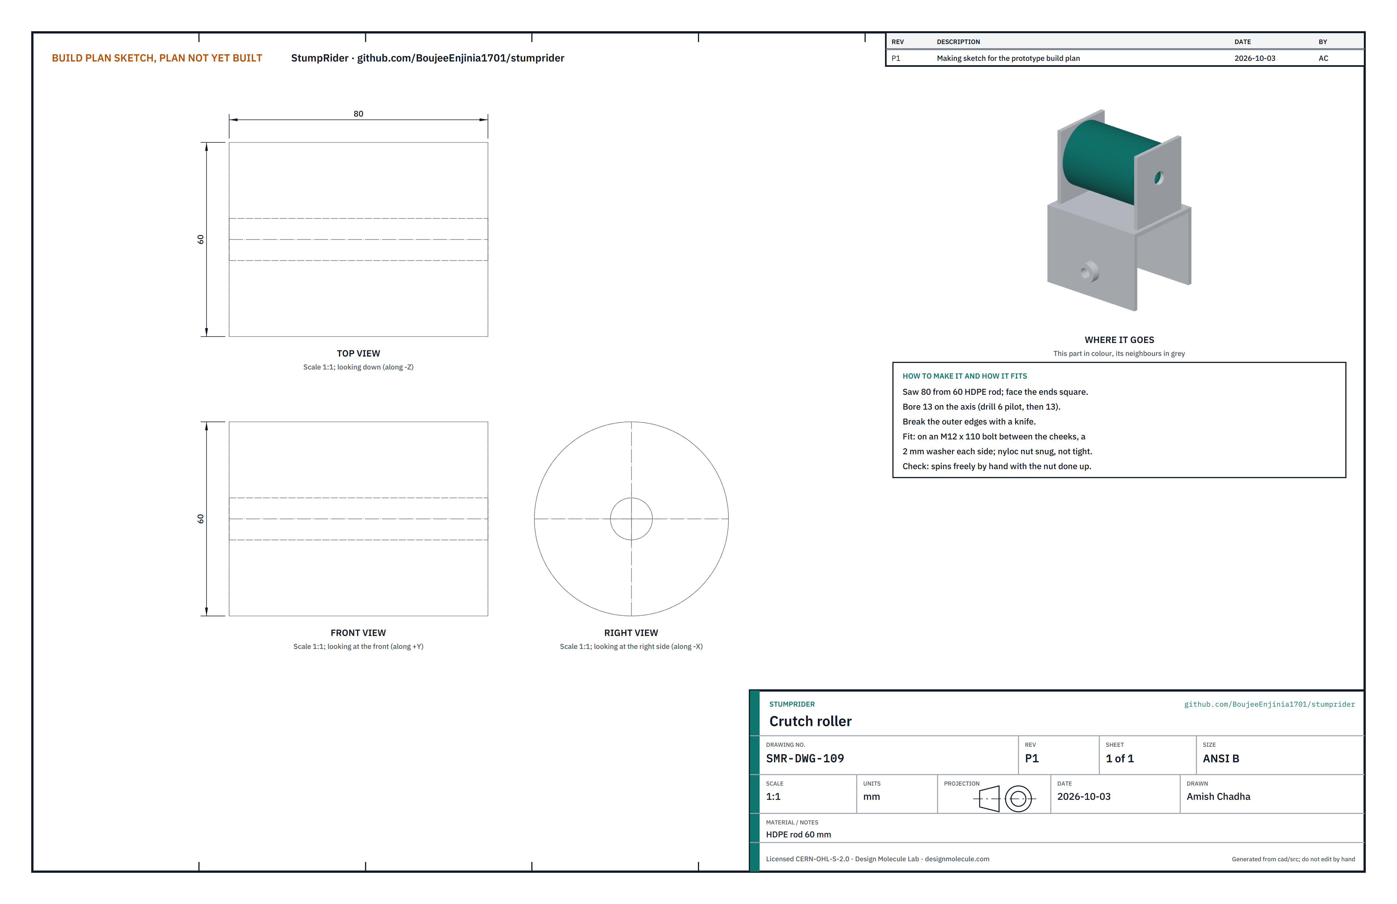
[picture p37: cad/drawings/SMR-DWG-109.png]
Making sketch: roller


**What it is and what it is made from.** An 80 length of 60 HDPE rod, bored to run on an M12 bolt.

**How to make it.**

1. Saw 80 from the rod; face the ends square.
2. Drill a 6 pilot on the axis, then open it to 13.
3. Take the sharp outer edges off with a knife.

**How it fits the parts next to it.** On an M12 x 110 bolt between the cheeks, with a 2 washer each side; the nyloc nut is snug, not tight.

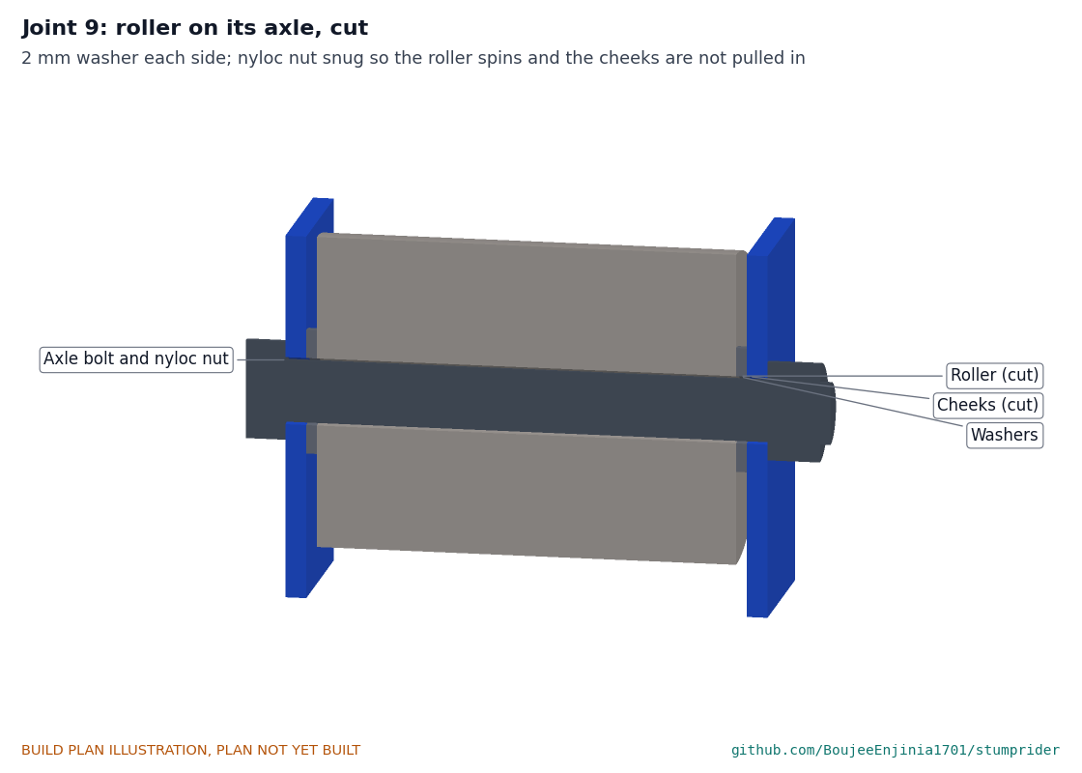
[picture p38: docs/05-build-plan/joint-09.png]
The roller on its axle, cut


*Figure 10. Roller, washers and axle bolt.*

**Check before moving on.** It spins freely by hand with the nut done up.

### 3.10 Crutch clamp screw (17)

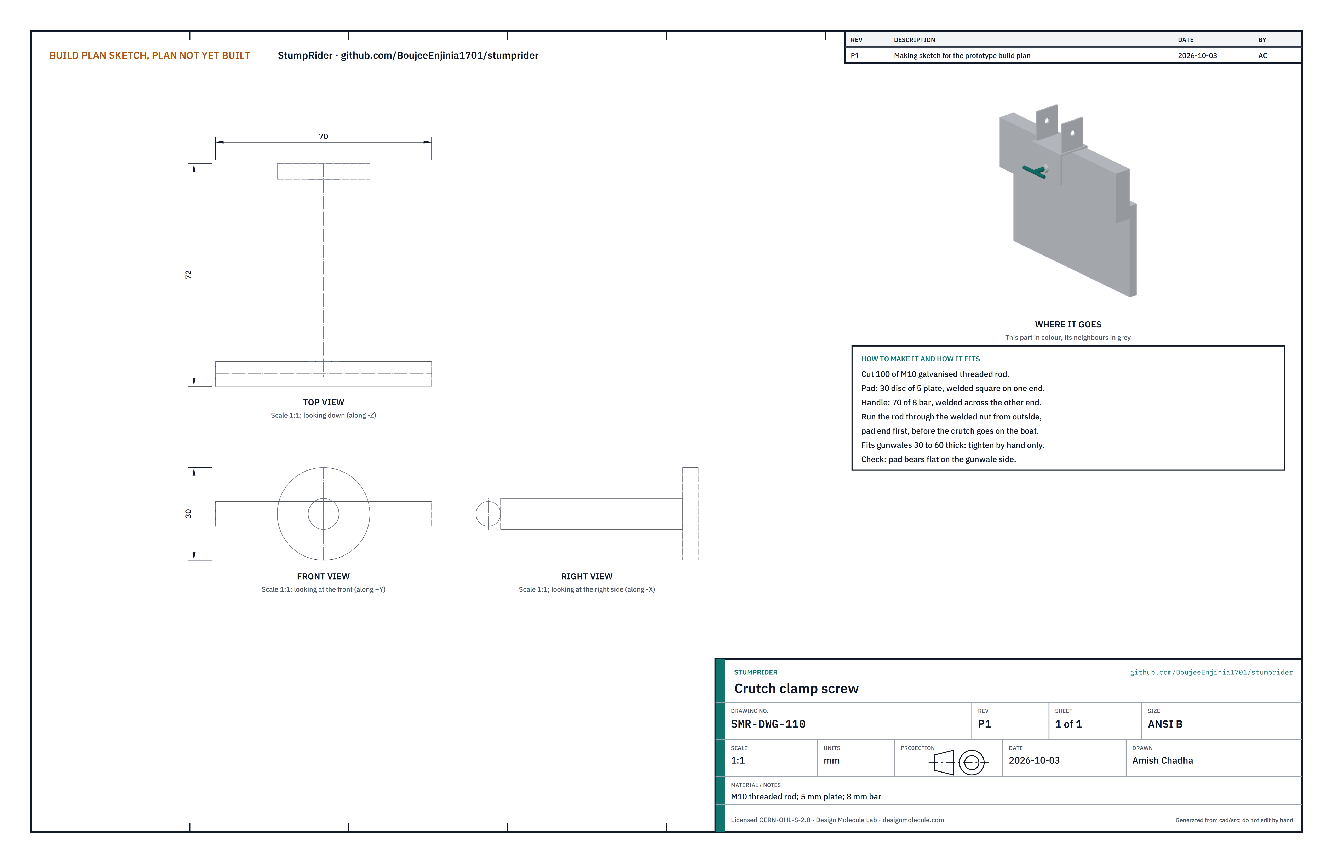
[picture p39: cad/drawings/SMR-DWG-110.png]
Making sketch: clamp screw


**What it is and what it is made from.** 100 of M10 galvanised threaded rod with a 30 pad on one end and a 70 handle across the other.

**How to make it.**

1. Cut 100 of M10 rod.
2. Weld a 30 disc of 5 plate square on one end (grind the zinc off the weld area first, outdoors).
3. Weld 70 of 8 round bar across the other end. Touch up the welds with zinc-rich paint.

**How it fits the parts next to it.** It runs through the nut on the crutch's inboard leg, pad end in first.

**Check before moving on.** It turns by hand through the full 30 to 60 range.

### 3.11 Hook head (21)

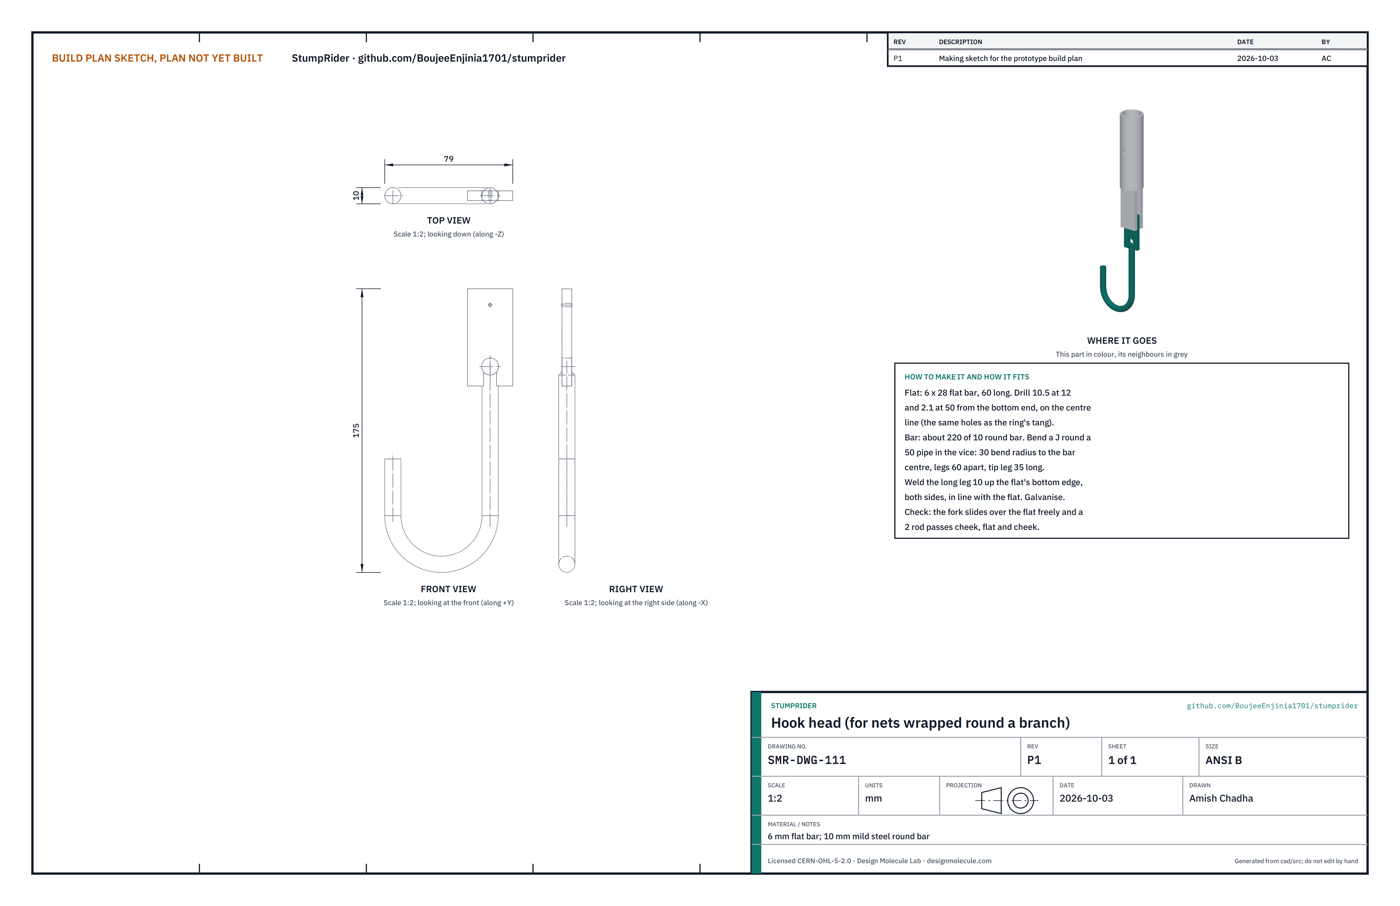
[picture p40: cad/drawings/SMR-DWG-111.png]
Making sketch: hook head


**What it is and what it is made from.** A J hook of 10 mm steel round bar welded to a short flat with the same holes as the ring's tang, so it pins into the same fork. It weighs about 0.2 kg.

**How to make it.**

1. Cut 60 of 6 x 28 flat bar. Drill a 10.5 hole 12 from one end and a 2.1 hole 50 from the same end, on the centre line.
2. Cut about 220 of 10 round bar. Bend one end round a 50 pipe held in the vice into a J: the legs end up 60 apart, centre to centre, with a 50 gap between them, and the short leg 35 long.
3. Weld the long leg to the flat, in line with it, running 10 up the flat's end with the 10.5 hole; weld both sides.
4. Galvanise with the other steel parts.

**How it fits the parts next to it.** The fork goes over the flat in place of the ring's tang, held by a calibrated shear pin; the tether's bowline is moved to the 10.5 hole so the hook comes back if the pin breaks.

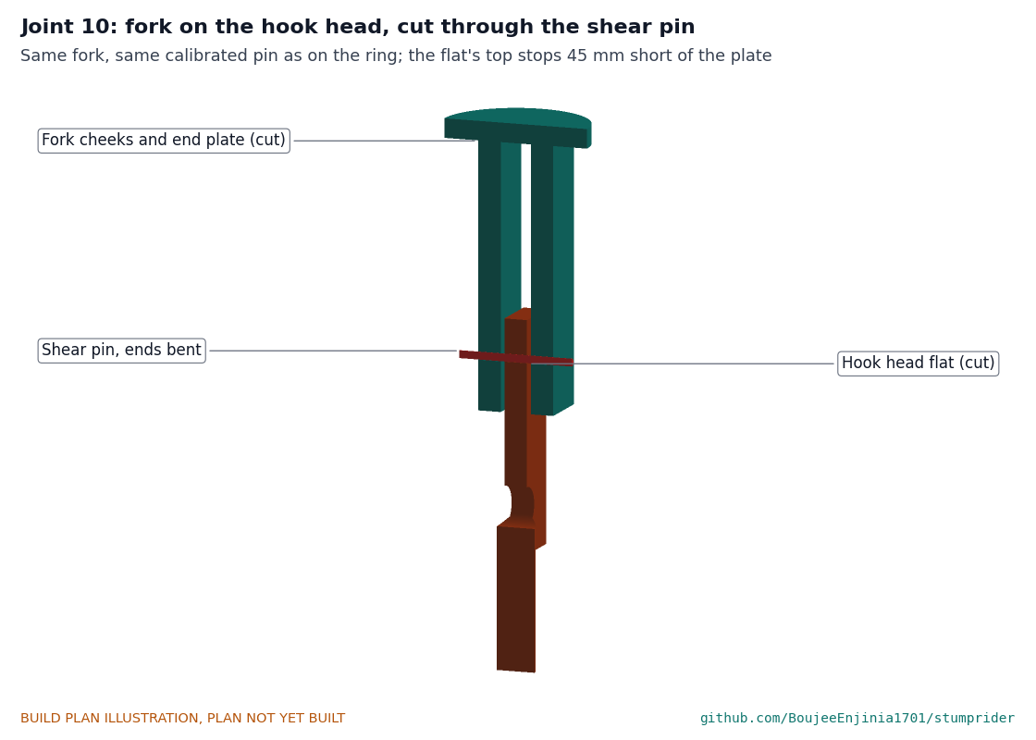
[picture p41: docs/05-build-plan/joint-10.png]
The fork on the hook head, cut


*Figure 11. The hook head in the fork, held by the same shear pin.*

**Check before moving on.** The fork slides over the flat freely; a 2 rod passes cheek, flat and cheek; the J's gap takes two fingers.

### 3.12 Bamboo local variant pole

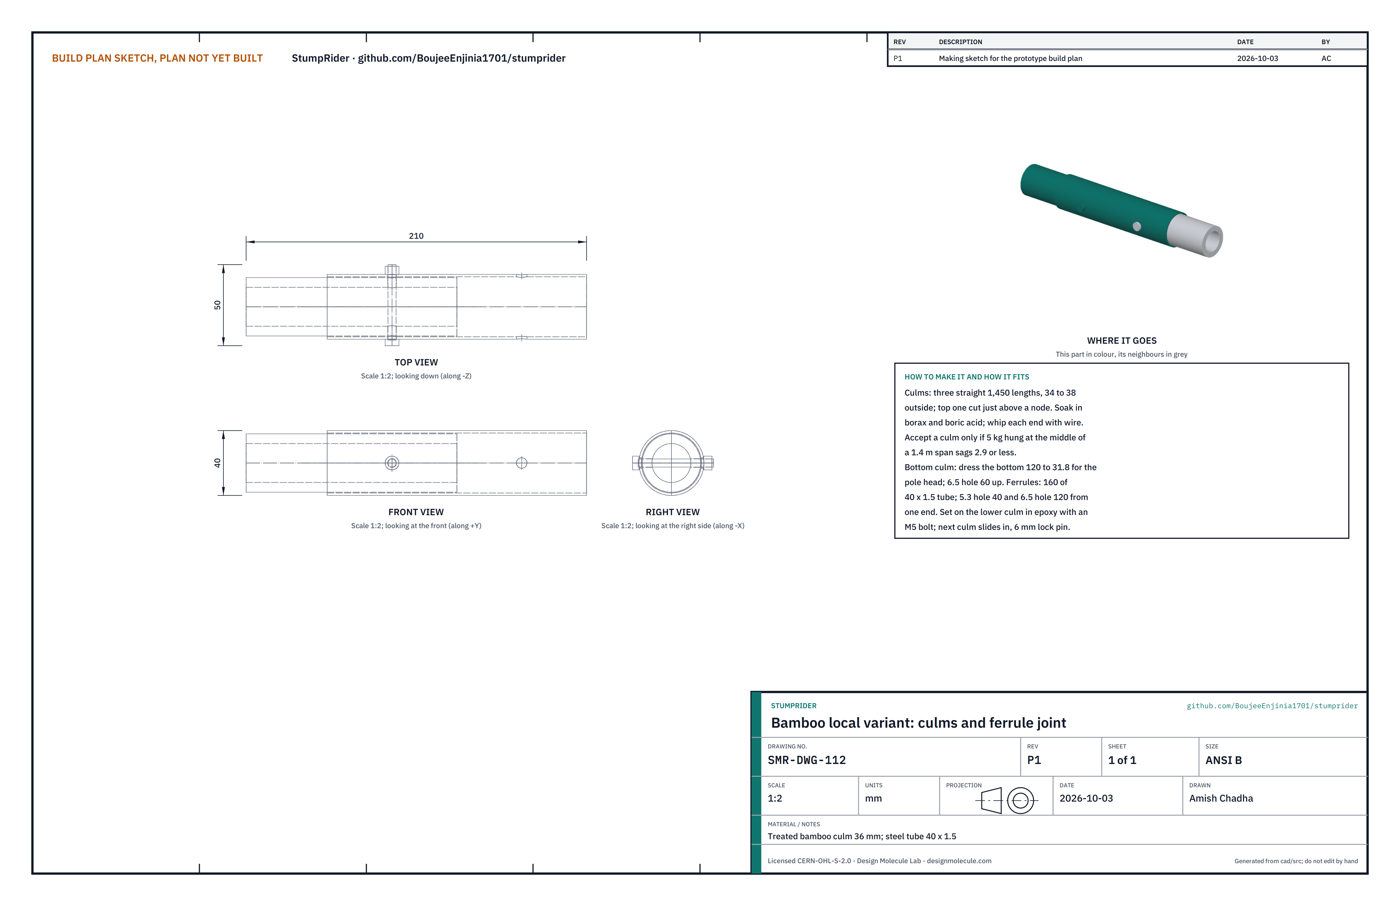
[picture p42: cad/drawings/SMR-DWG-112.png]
Making sketch: bamboo culms and ferrule joint


**What it is and what it is made from.** A pole of three bamboo culms in place of the aluminium sections, sleeves, rivets and grip cap (`bom/bom-bamboo-variant.csv`). Straight seasoned culms about 36 across (34 to 38), 1,450 long; two ferrules of 40 x 1.5 steel tube, 160 long; two M5 stainless bolts with nyloc nuts; epoxy. The ring, pole head, pins, hook head, tether and float are the same as in the aluminium kit.

**How to make it.**

1. Choose culms that are straight and free of splits. Bend-test each: rest it on two supports 1.4 apart and hang 5 kg at the middle. Use it only if it sags 2.9 or less.
2. Cut three 1,450 lengths. Cut the top one just above a node so the node closes its end.
3. Soak the culms in a borax and boric acid solution for a week, then dry them in the shade. Whip each end with galvanised wire.
4. Dress the bottom 120 of the bottom culm down to 31.8 with a rasp and file until it slides into the pole head. Drill 6.5 across it, 60 from the bottom end.
5. Cut two 160 lengths of 40 x 1.5 tube; deburr. Drill 5.3 across, 40 from one end, and 6.5 across, 120 from the same end. Paint with zinc-rich paint.
6. Push a ferrule 80 onto the top of the bottom culm, bolt end first, with epoxy on the culm. Drill 5.3 through the culm through the ferrule's hole and fit an M5 bolt and nyloc nut. Do the same on the middle culm.
7. Push the next culm into each ferrule until it butts, and drill 6.5 through it through the ferrule's lock pin hole.

**How it fits the parts next to it.** The bottom culm goes into the pole head and is held by the head lock pin; the culms are joined by the ferrules and the same 6 mm lock pins as the aluminium pole.

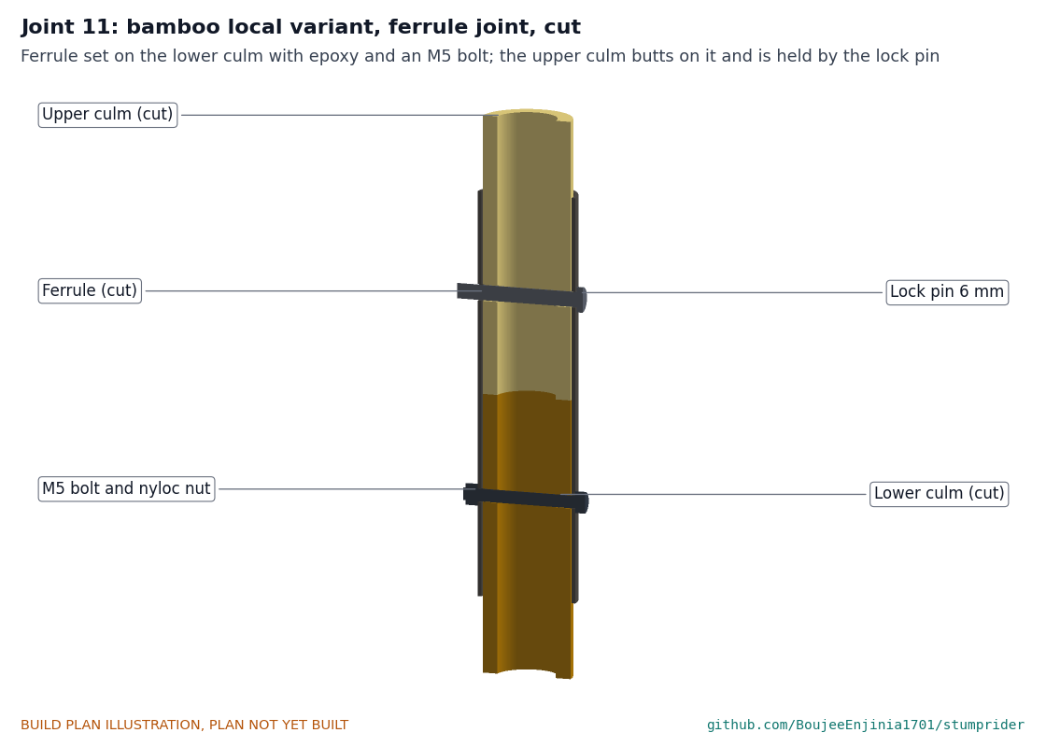
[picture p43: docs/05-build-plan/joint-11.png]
The ferrule joint, cut


*Figure 12. Ferrule joint: bolted and glued below, pinned above.*

**Check before moving on.** Every culm passed the bend test; the joints have no play you can feel; the longest piece packs under 1.6 m.

### 3.13 Bought components

- **Hinge bolt (2):** M8 x 30 stainless bolt, nyloc nut and two washers.
- **Gate pin (3):** 8 x 30 stainless clevis pin with an R-clip; tie a 300 length of 3 cord through the R-clip and round the gate ear.
- **Pop rivets (8):** four 4.8 stainless blind rivets, grip 4 to 6.
- **Lock pins (9):** four 6 x 50 stainless clevis pins with R-clips; tie a short lanyard to each.
- **Grip cap (10):** rubber cap for 32 tube, 30 deep.
- **Tether cord (11):** 10 m of 6 braided polyester; heat-seal both ends.
- **Spare pin tube (13):** a small capped vial about 14 across and 80 long; tie it to the winder.

## 4. Putting it together

### Step 1: hinge the ring halves

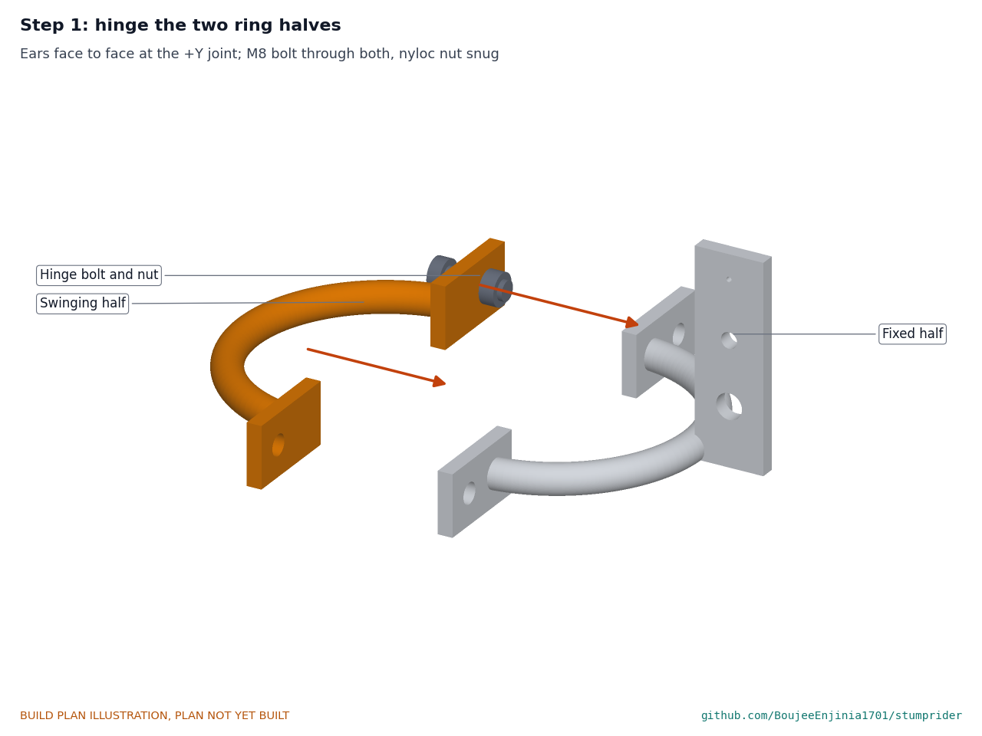
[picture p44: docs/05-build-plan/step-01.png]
Step 1


Lay the halves together with the hinge ears face to face. Push the M8 bolt through, add the nyloc nut and tighten until the swinging half still moves under its own weight.

### Step 2: close the gate

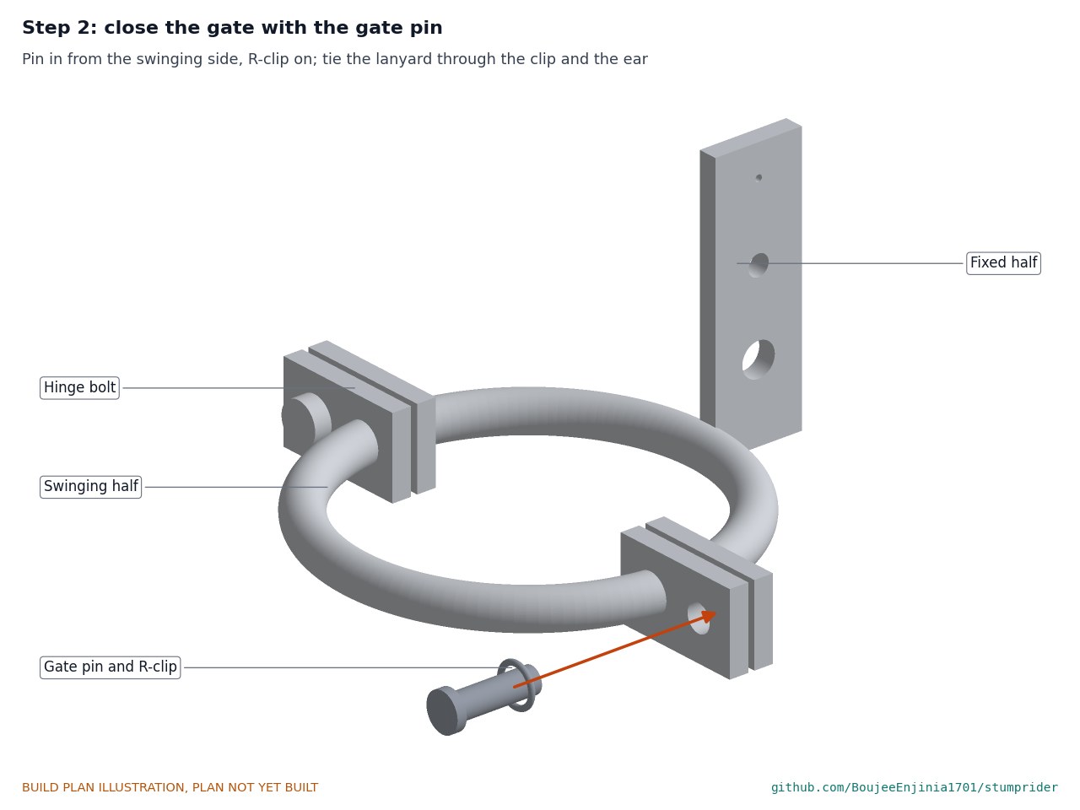
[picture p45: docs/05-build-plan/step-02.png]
Step 2


Swing the halves shut, push the gate pin in from the swinging side and fit the R-clip. Tie the lanyard through the R-clip and round the ear.

### Step 3: tie on the tether

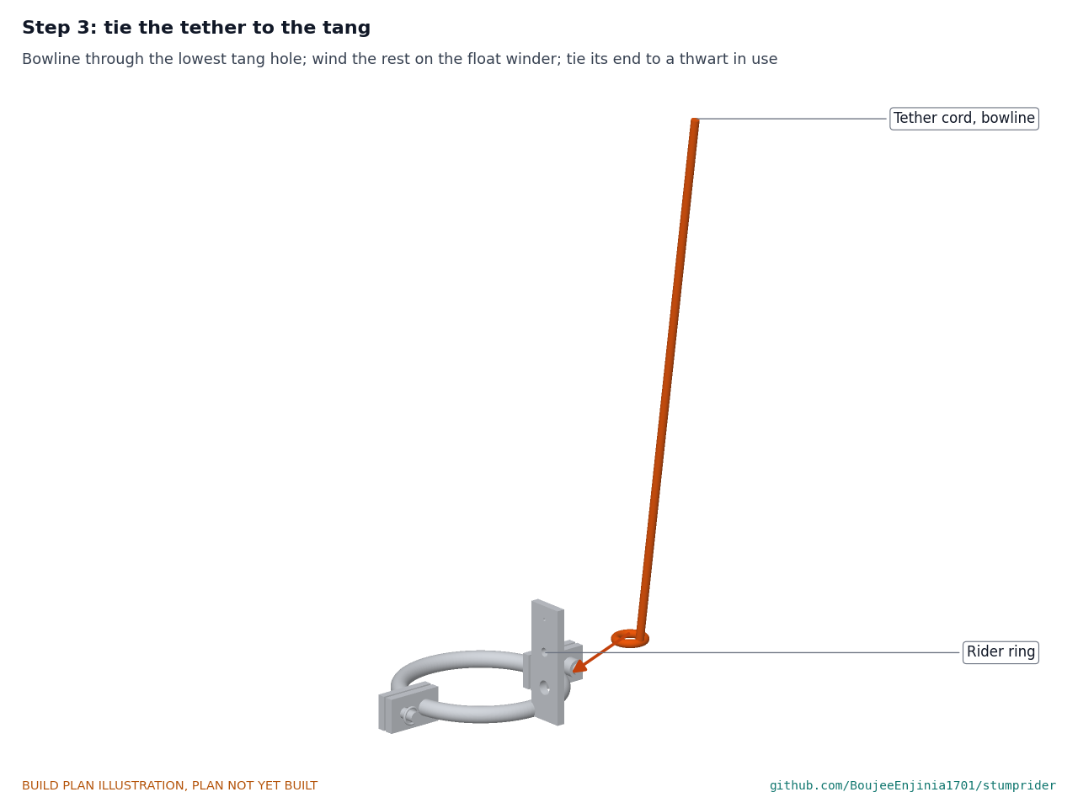
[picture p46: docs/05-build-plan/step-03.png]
Step 3


Tie the cord's end through the tang's lowest hole with a bowline round the tang's outer edge. Wind the rest on the float winder and tie the far end through the winder's hole.

### Step 4: rivet the sleeves

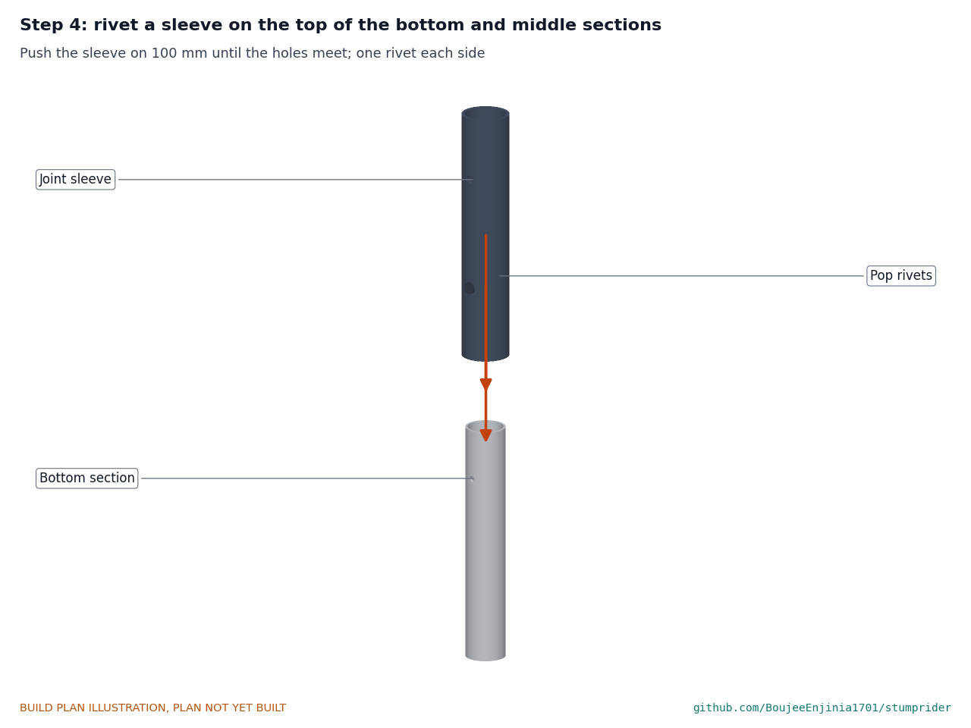
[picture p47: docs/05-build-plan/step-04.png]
Step 4


Push a sleeve 100 onto the top of the bottom section until the rivet holes meet; fit one rivet each side. Do the same on the middle section. Hold point: pull each sleeve by hand; it must not move.

### Step 5: fit the pole head

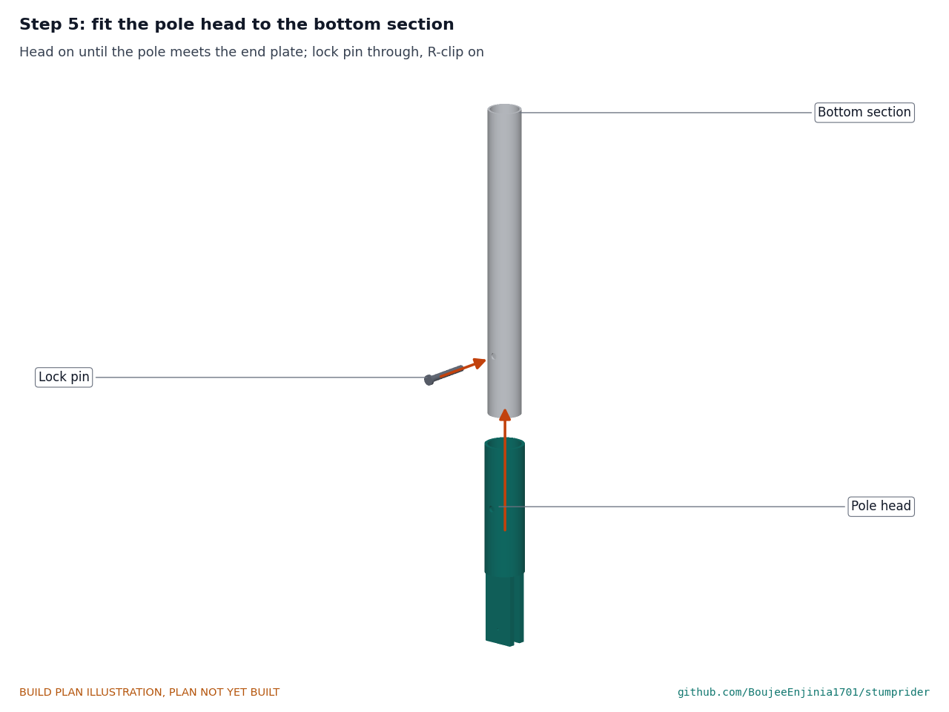
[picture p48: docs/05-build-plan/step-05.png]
Step 5


Push the head onto the bottom of the bottom section until the pole rests on the end plate. Fit a lock pin through and its R-clip.

### Step 6: join the sections

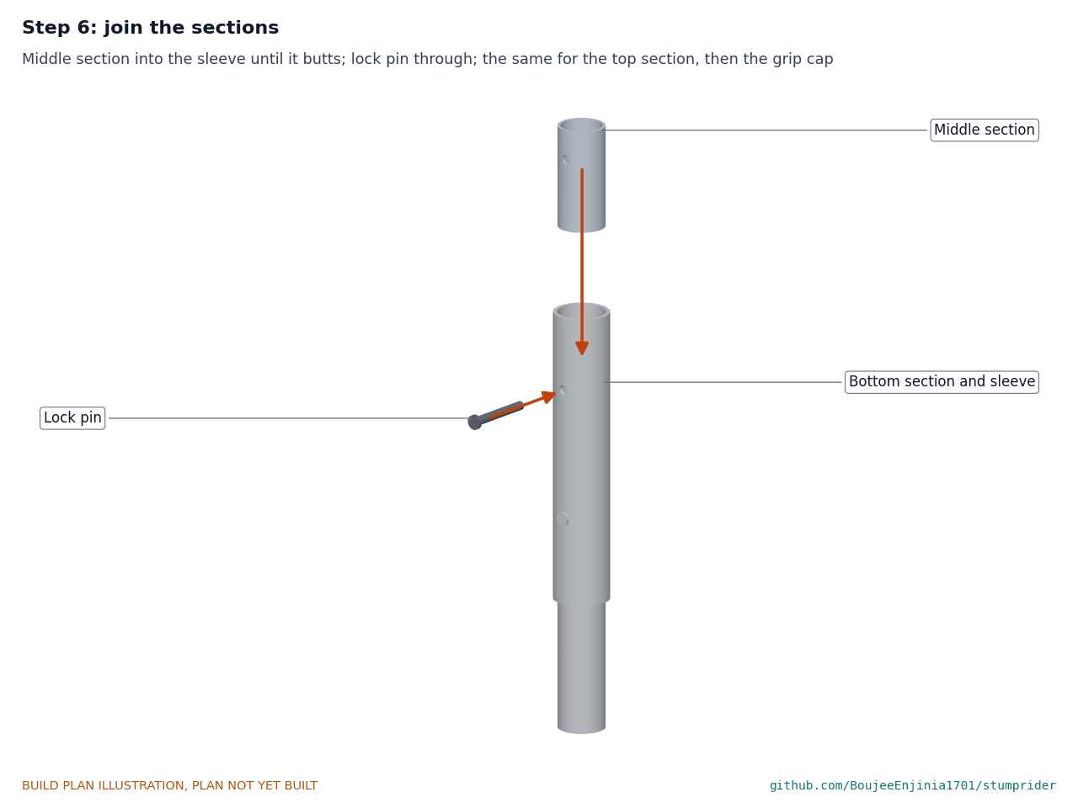
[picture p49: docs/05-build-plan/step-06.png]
Step 6


Push the middle section into the bottom section's sleeve until it butts; fit a lock pin. Push the top section into the middle sleeve the same way and fit a lock pin. Push the grip cap on the top.

### Step 7: fork on the tang, shear pin in

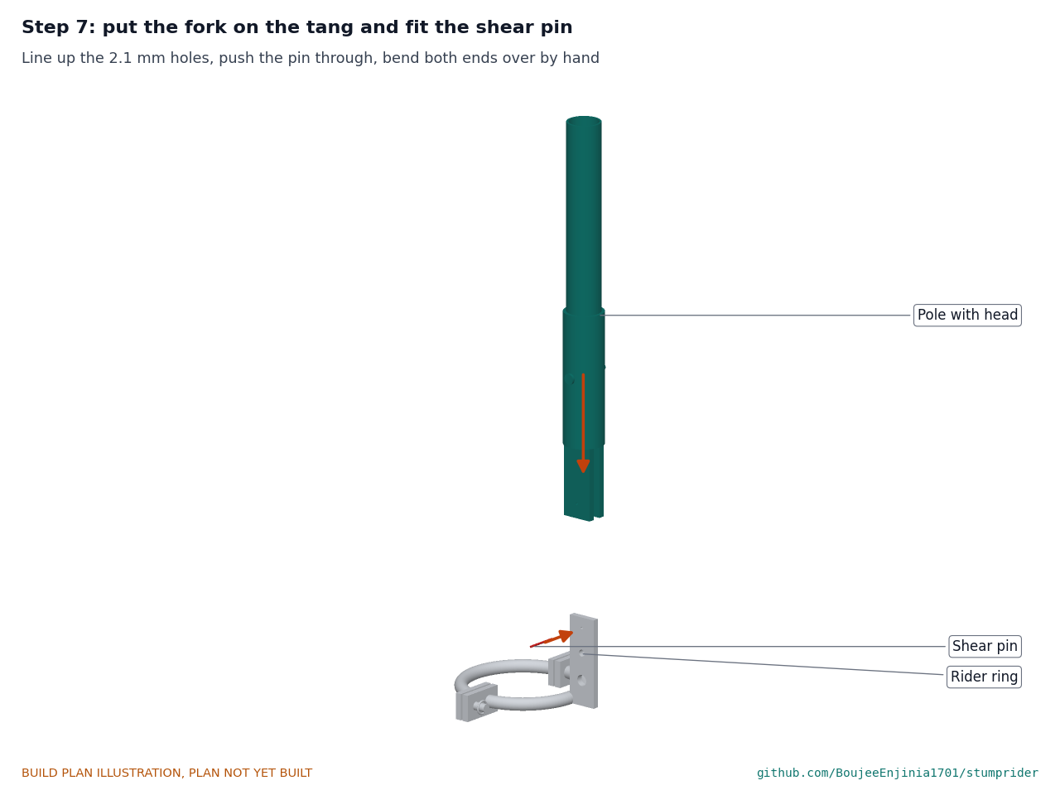
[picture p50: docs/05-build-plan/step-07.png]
Step 7


Slide the fork over the ring's tang, line up the 2.1 holes, push a calibrated shear pin through and bend both ends over by hand. Hold point: never fit anything but a calibrated pin.

### Step 8: fit the roller

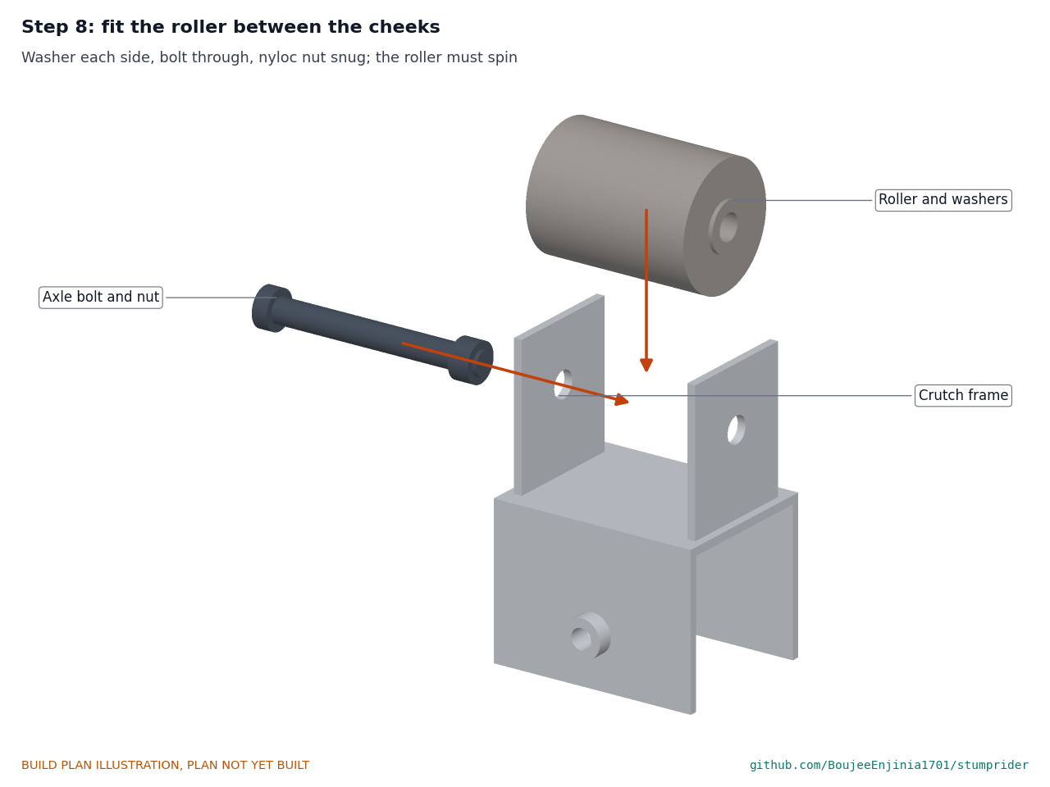
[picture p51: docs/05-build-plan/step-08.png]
Step 8


Put the roller between the cheeks with a washer each side, push the axle bolt through and do up the nyloc nut until it is snug; the roller must still spin.

### Step 9: fit the clamp screw

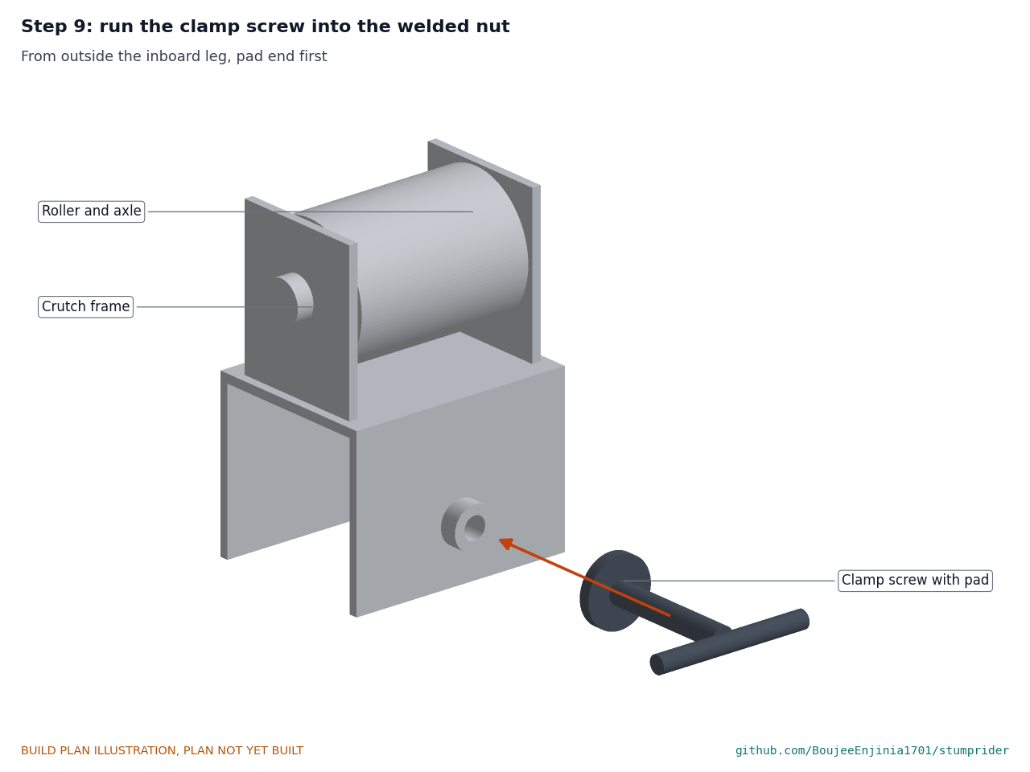
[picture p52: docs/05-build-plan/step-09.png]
Step 9


Run the clamp screw into the welded nut from outside the inboard leg, pad end first, until the pad is just inside the leg.

### Step 10: clamp the crutch on the canoe

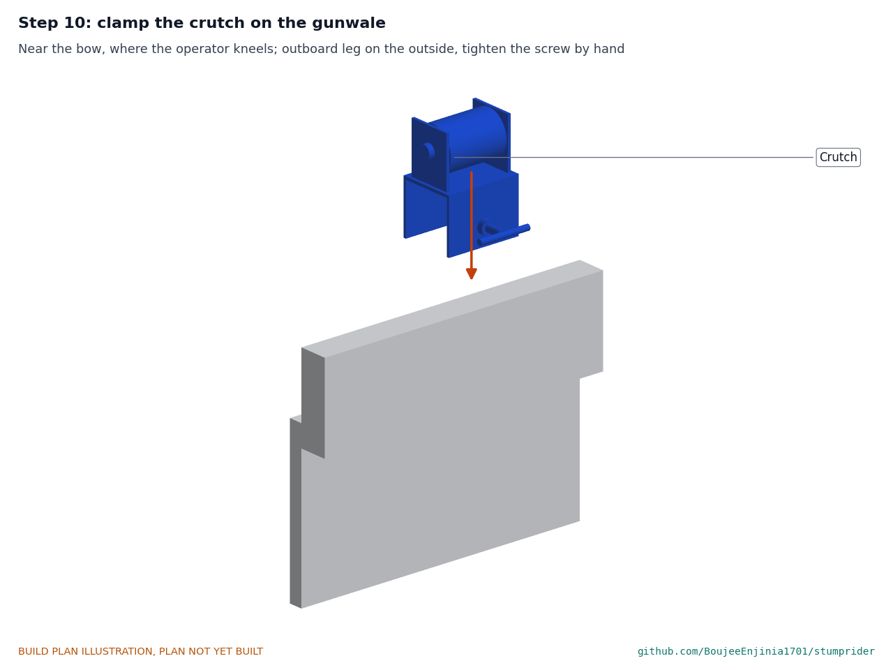
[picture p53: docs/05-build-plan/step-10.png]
Step 10


Near the bow, where the operator will kneel, set the web on the gunwale with the outboard leg against the outside. Tighten the clamp screw by hand. Hold point: the crutch must not move when pulled hard by hand. The crutch stays on the canoe as a fitting; it is not carried home with the kit.

### Step 11: jigging set-up (deep snags only)

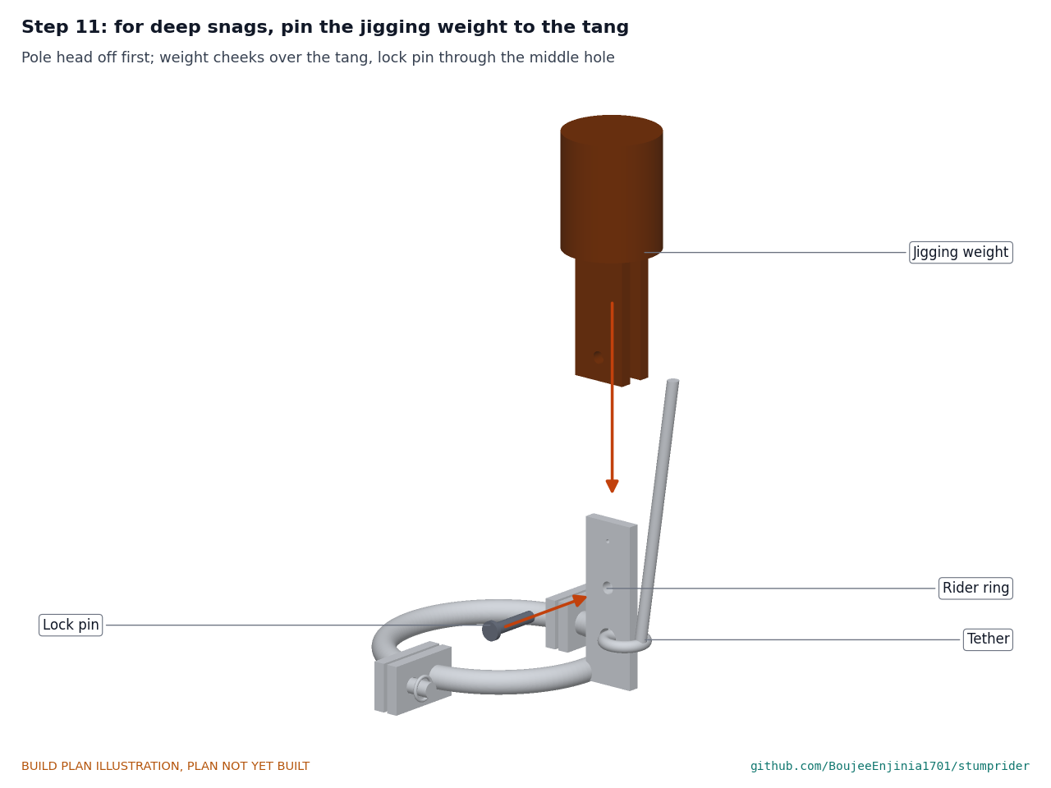
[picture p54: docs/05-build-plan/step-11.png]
Step 11


The jigging weight is kept at the landing and taken out only for a known deep set. Take out the shear pin and lift the pole head off the tang. Put the jigging weight's cheeks over the tang and fit a lock pin through the middle hole. Tie the tether's end to a thwart before working.

### Step 12: hook head (net wrapped round a branch)

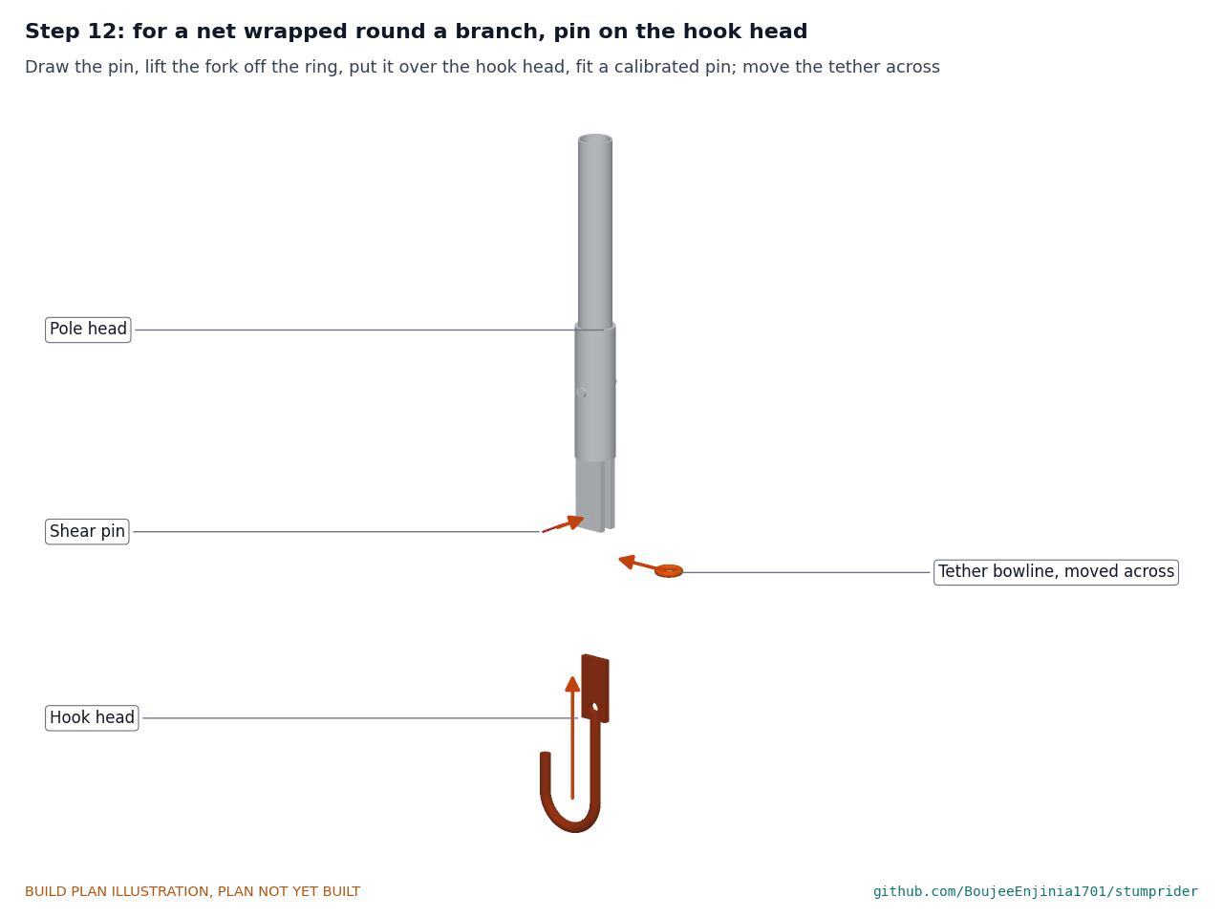
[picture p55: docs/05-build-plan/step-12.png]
Step 12


When the ring will not lift a net that has wrapped round a branch, bring the ring back up the line. Draw the shear pin, lift the fork off the ring's tang and put it over the hook head's flat; push a calibrated pin through and bend its ends. Untie the tether's bowline from the ring and tie it through the hook head's 10.5 hole. Reach down beside the net line, hook the bight of net where it goes round the branch and pull it back the way it wrapped, half a turn at a time, with the crew's line slack. Then change back to the ring and lift the net off. Hold point: the same rules apply as with the ring: kneel, slacken the line, and cut the net if the canoe heels.

## 5. First checks

*Table 2. First checks, listed here and recorded in a TRL 4 test report.*

| # | Check | Requirement | How | Pass when |
| --- | --- | --- | --- | --- |
| 1 | Pin calibration | R3 | Break ten pins from the reel in a test fork on CalRig, pulling slowly | All ten break between 256 and 347 N; otherwise change the wire diameter and repeat |
| 2 | Ring fit | R6 | Close the ring on lines of 4, 8, 12 and 16 mm; slide it 1 m along each | Closes on every line and slides without catching |
| 3 | Pole and joints | R2, R7 | Assemble, measure from 300 below the cap to the ring centre; pack the sections | At least 4.0 m; longest piece under 1.6 m; joints have no play you can feel |
| 4 | Release on a bench snag | R1, R3 | Ring on a rope hooked over a fixed log, crew rope at 30 N, pull up the pole on a spring balance | Rope lifts clear below the pin rating, or the pin breaks inside its band and the pole comes away cleanly |
| 5 | Mass | R7 | Weigh the kit carried to and from the canoe (without the crutch and the jigging weight), aluminium and bamboo | Recorded against R7 (4 kg) |
| 6 | Float | R7, R8 | Hang the ring and cord on the winder in water | Floats |
| 7 | Canoe heel | R3 | With the canoe moored in shallow, calm water, crew aboard in life jackets, pull the pole sideways from a fixed point ashore with a spring balance up to the pin rating; read the heel with an inclinometer | Heel at 347 N is 5 deg or less |
| 8 | Hook head on a bench wrap | R1 | Rope wrapped once round a fixed log, crew rope at 30 N; work it back with the hook head, then lift with the ring | The wrap comes back half a turn below the pin rating, or the pin breaks inside its band |
| 9 | Bamboo pole | R2, R7 | Bend-test every culm; assemble and repeat check 3 | Every culm sags 2.9 mm or less; reach and packed length as check 3 |

## 6. Safety stops

Work stops at each of these points and goes on only when everything listed is true.

- **S1, before welding:** working in the open, nothing galvanised in the weld zone, eye and hand protection on.
- **S2, before fitting any shear pin:** its reel has passed check 1; no other pin, nail, bolt or wire is in the kit.
- **S3, before taking the kit onto a canoe:** checks 2 to 6 passed; the crutch is clamped and pulled by hand; every person has a life jacket on.
- **S4, before the heel test (check 7) or any use on a snag:** the canoe is at least 7 m long with at least three crew (a smaller canoe class only once heel tests have set a pin for it), moored or in shallow, calm water; the operator kneels; the crew knows to slacken the line when the operator lifts and to cut the net if the canoe heels; nobody enters the water for any reason.
- **S5, after every pin break:** the operator is back in a kneeling position, the ring or hook head is recovered on its tether, and a calibrated pin is fitted before the next try.

## 7. Tools, skills and workspace

- Tools: hacksaw or cut-off grinder, rasp and files for bamboo, a 5 kg weight for the bend test, bench drill or hand drill with a vee block, drills from 2.1 to 13, a vice, a 100 mm round former, files and a flap disc, stick welder, pop rivet gun, sharp knife, tape and square, spring balance to 50 kg, bubble inclinometer.
- Skills: basic bending and welding of mild steel; drilling square through tube; tying a bowline.
- Workspace: an open-air workshop bench; a galvaniser for the steel parts (sent out once all welding is done); a calm, shallow mooring for check 7.

## 8. Where the numbers come from

- Model: `cad/src/model.py` (sizes, constructability checks), STEP files in `cad/step/`.
- Drawings: `cad/drawings/SMR-DWG-001` (general arrangement) and `SMR-DWG-101` to `SMR-DWG-112` (making sketches).
- Calculations: `docs/04-calcs/01-sizing.md` (SMR-CAL-001), `docs/04-calcs/sizing.py` and `docs/04-calcs/results.csv`.
- Bill of materials: `bom/bom.csv`; bamboo local variant `bom/bom-bamboo-variant.csv`.
- Pictures: `cad/src/build_plan_media.py`.

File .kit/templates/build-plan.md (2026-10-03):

---
doc_id: PRJ-BLD-001
title: Project prototype build plan
project: Project name
doc_type: Build plan
version: "0.1"
status: Draft
date: YYYY-MM-DD
author: Amish Chadha
license: CERN-OHL-S-2.0
revisions:
  - version: "0.1"
    date: YYYY-MM-DD
    author: Amish Chadha
    change: First build plan; design made constructable
---

# Project prototype build plan

**Plan, not yet built.** How to build the first proof-of-concept prototype, component by component. Building and testing to it is TRL 4 work. Decisions still to be made are kept in the design decisions register (`docs/06-design-decisions.md`), not here.

## 1. What you are building

Every component, pulled apart and numbered in build order

One short paragraph: what the prototype is, how many components, which are made and which are bought, and the main ways they are made.

## 2. What changed to make it buildable

| Component | The concept had | The buildable design has | Why |
| --- | --- | --- | --- |

## 3. Making the components

### 3.1 Component name

Making sketch

**What it is and what it is made from.**

**How to make it.**

1. Mark out ...
2. Cut ...

**How it fits the parts next to it.**

Close-up of the joint

**Check before moving on.**

## 4. Putting it together

### Step 1: ...

Step 1

## 5. First checks

| Check | Requirement | How | Pass when |
| --- | --- | --- | --- |

## 6. Safety stops

## 7. Tools, skills and workspace

## 8. Where the numbers come from

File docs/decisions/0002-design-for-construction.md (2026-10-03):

---
doc_id: SMR-DDR-002
title: StumpRider design for construction
project: StumpRider
doc_type: Design decision record
version: "0.1"
status: Draft
date: '2026-10-03'
author: Amish Chadha
license: CERN-OHL-S-2.0
revisions:
- version: "0.1"
  date: '2026-10-03'
  author: Amish Chadha
  change: Design made constructable; changes C1 to C12 and assumptions A1 to A5 decided under Amish's 2026-10-03 pre-approvals
---

# 0002: Design for construction

- **Date:** 2026-10-03
- **Status:** decided. Decided by Amish under his pre-approval of 2026-10-03: "start with the first 14 repos from the list of 29 projects. I pre-approve the batch runs along with any recommendations you come up with. I also accept any cost overruns or variations from the assumed scope cost." and "Proceed with the remaining 15 scaffolds".

> **Safety:** C2 and C3 make the shear pin the only link between the pole and the ring, so the safety limit cannot be bypassed by the tang bottoming in the fork. Nothing here changes the safety case of SMR-DDR-001.

## Context

STANDARDS section 18 asks that every part can be made by a stated process and fits and fastens to its neighbours. The TRL 1 concept named a "split rider ring" closed by a "captive pin", a "jointed push pole", a "pole head with shear pin", a "jigging weight" used on the tether cord and a "gunwale roller or crutch", but did not say how the ring opens, what the pin passes through, how the pole joints lock, or how the crutch holds on a canoe. The constructability review of the model (`cad/src/model.py`, 80 checks: overlaps, contacts of every pin and rivet in its holes, fork clearances on the tang, slide fit of the sleeves, the tang's clearance under the end plate, the crutch on 30, 40 and 60 mm gunwales, packed length) led to the changes below. None changes what the product does or its pitch.

## Changes

*Table 1. Changes made for construction.*

| # | The concept had | The constructable design has | Why |
| --- | --- | --- | --- |
| C1 | A split ring with a captive pin | Two half rings of 12 mm bar, 2 mm gaps at the joints; each end carries a 6 x 25 x 42 mm ear; M8 hinge bolt at one joint, 8 mm clevis gate pin with R-clip and lanyard at the other | A one-piece C ring with a pin across its gap cannot open far enough to take a line; hinged halves open fully |
| C2 | "Pole head with shear pin" | A 38 x 3 mm steel socket on a 6 mm end plate, with two 6 x 30 mm fork cheeks 8 mm apart welded under it | Gives the pin two shear planes and a known geometry; the pole bears on the end plate |
| C3 | No connection on the ring | A 6 x 28 x 84 mm tang welded on the outside of the fixed half, with 10.5, 6.5 and 2.1 mm holes (tether, jigging weight, shear pin); its top stops 45 mm below the end plate | The fork straddles the tang; the gap keeps push and pull on the pin; twisting bears on the cheeks |
| C4 | "Two or three sections" | Three 1,450 mm sections of 32 x 2 mm tube; 200 mm sleeves of 38 x 2.8 mm tube riveted (two 4.8 mm rivets) to the lower section of each joint; 6 mm lock pin through sleeve and upper section | Packed length 1.55 m; the joint cannot pull apart or twist |
| C5 | Head fixed on the pole | Head held on the bottom section by a 6 mm lock pin | It comes off for packing and for jigging |
| C6 | Open pole top | Rubber grip cap | Keeps water out and gives a grip |
| C7 | "Tether cord and float" | 10 m of 6 mm cord tied with a bowline through the tang's lowest hole; 300 x 120 x 40 mm foam winder with end notches; spare pin vial tied to it | A defined attachment and a float that holds the ring and cord |
| C8 | Jigging weight "used on the tether cord" | 50 mm steel bar 60 mm long with fork cheeks, pinned to the tang's middle hole with a lock pin, pole head off | A weight loose on the cord would not move the ring |
| C9 | "Gunwale roller or crutch" | 4 mm steel U saddle, 70 mm inside, over the gunwale; two cheeks carrying an 80 mm HDPE roller on an M12 bolt with 2 mm washers; M10 clamp screw with a pad through a nut welded on the inboard leg | Fits gunwales 30 to 60 mm thick without drilling the canoe |
| C10 | Materials open | Mild steel parts hot-dip galvanised after welding; stainless pins and rivets; 6063-T6 aluminium; HDPE; closed-cell polyethylene foam; polyester cord | R8 wet storage |
| C11 | Pin length open | Shear pins 30 mm long, ends bent over by hand after fitting | Holds the pin without a clip that could add strength |
| C12 | No marking | Pin rating painted on the socket; top 300 mm of the pole and the float painted orange | The rating is visible; a dropped part is easy to see |

## Assumptions

*Table 2. Assumptions to confirm when parts are bought (listed in SMR-DEC-001).*

| # | Assumption | Effect if wrong |
| --- | --- | --- |
| A1 | 38 mm tube with a 32.4 mm bore can be bought, or 38 x 3 mm tube opened to a slide fit | Sleeve fit; the lock pin holes must still line up |
| A2 | The pin wire shears at about 48 MPa | The pin diameter is changed to bring ten test pins into the 256 to 347 N band |
| A3 | Gunwales are 30 to 60 mm thick and have 70 mm of clear side below the top | The saddle width or leg depth changes |
| A4 | The design canoe (8 m, three crew, 550 kg) is typical of the first fishery | The heel check is redone with measured data |
| A5 | Bent 12 mm bar holds a 112 mm mean diameter within 2 mm | The joint gaps are trimmed to 2 mm before the ears are welded |

## Consequences

- 80 of 80 constructability checks pass in the model.
- The kit mass rises to 6.5 kg and the cost to USD 92.50 a kit (R7 and R10, decisions for Amish).
- STEP and STL files, the general arrangement (SMR-DWG-001, Rev P2), the making sketches (SMR-DWG-101 to 110), the concept media and the build plan (SMR-BLD-001) all come from the changed model.

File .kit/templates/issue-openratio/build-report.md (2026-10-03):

---
name: Build report
about: Tell us what happened when you built, printed or tested part of this design
title: "Build report: "
labels: build-report
---

This is a research and educational prototype, not a medical device. It is a TRL 3 concept and is not released for fabrication. If you build any part of it, you do so at your own risk. Reports help everyone.

**What you built** (part, sub-assembly or test)

**Materials, tools and settings**

**What worked**

**What did not work, with photos or measurements if you have them**

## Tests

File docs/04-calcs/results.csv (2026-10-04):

tag | item | value | unit | requirement | status
M1 | Rider ring with hinge bolt and gate pin | 0.612 | kg
M2 | Pole head | 0.557 | kg
M3 | Three pole sections, two sleeves, rivets, lock pins, cap | 2.612 | kg
M4 | Jigging weight | 1.116 | kg
M5 | Gunwale crutch (frame, roller, axle, clamp) | 1.379 | kg
M6 | Tether cord, float winder, spare pins | 0.293 | kg
M7 | Working tool (ring, head, pole, pins) | 3.784 | kg
M8 | Whole kit, including the crutch and jigging weight | 6.777 | kg
M9 | Longest packed piece (a section with its sleeve) | 1550.0 | mm | R7 | met
M10 | Hook head (SMR-DDR-003) | 0.205 | kg
M11 | Carried kit, aluminium prototype: crutch stays clamped on the canoe, jigging weight kept at the landing | 4.282 | kg | R7 | not met
P1 | Shear pin rating, 2.0 mm soft aluminium in double shear (nominal) | 301.593 | N
P2 | Pin band allowed by R3, low | 256.354 | N
P3 | Pin band allowed by R3, high (used for every safety check) | 346.832 | N
H1 | design canoe: displacement | 550.0 | kg
H2 | design canoe: metacentric height GM | 0.693 | m
H3 | design canoe: freeboard; heel that puts the gunwale under | 461.111 | mm
H4 | design canoe: gunwale immersion angle | 39.976 | deg
H5 | design canoe: heel when the pin breaks at the top of its band, kneeling | 3.409 | deg | R3 | met
H6 | design canoe: heel when the pin breaks at the top of its band, standing | 4.411 | deg | R3 | met
H7 | design canoe: pole pull that heels the canoe 5 deg, kneeling | 522.556 | N
H8 | design canoe: pole pull that heels the canoe 5 deg, standing | 396.098 | N
K1 | small dugout: displacement | 280.0 | kg
K2 | small dugout: metacentric height GM | 0.149 | m
K3 | small dugout: freeboard; heel that puts the gunwale under | 299.158 | mm
K4 | small dugout: gunwale immersion angle | 38.581 | deg
K5 | small dugout: heel when the pin breaks at the top of its band, kneeling | 23.673 | deg | R3 | outside the 7 m rule (SMR-DDR-003)
K6 | small dugout: heel when the pin breaks at the top of its band, standing | 34.087 | deg | R3 | outside the 7 m rule (SMR-DDR-003)
K7 | small dugout: pole pull that heels the canoe 5 deg, kneeling | 53.439 | N
K8 | small dugout: pole pull that heels the canoe 5 deg, standing | 37.431 | N
F1 | Pull to lift a hooked net, low friction (mu 0.3) | 81.327 | N
F2 | Pull to lift a hooked net, high friction (mu 0.5) | 126.21 | N | R1 | met
F3 | Pull to lift a net wrapped once round, low friction | 368.04 | N
F4 | Pull to lift a net wrapped once round, high friction | 2256.356 | N | R1 | at risk
F5 | Margin of the low end of the pin band over the hooked case, high friction | 2.031 | x
F7 | Pull to lift once the hook has worked the wrap back half a turn (one full turn left), mu 0.3 | 161.721 | N
F8 | Pull to lift once the hook has worked the wrap back half a turn (one full turn left), mu 0.5 | 492.814 | N
F6 | Pull if the crew keeps full tension while the operator lifts (hooked, high friction) | 196.21 | N
R1 | Working length, top hand to ring centre | 4.181 | m | R2 | met
R2 | Ring depth below the surface at 20 deg lean, kneeling | 3.168 | m
R3 | Tether reach below the surface, jigging | 8.0 | m | R2 | met
R4 | Ring inside diameter | 100.0 | mm | R6 | met
S1 | Euler buckling load of the whole pole, pinned ends | 766.567 | N
S2 | Buckling factor over the top of the pin band (push) | 2.21 | x
S3 | Lock pin factor, 6 mm stainless in double shear | 48.913 | x
S4 | Pole wall bearing factor at a lock pin hole | 22.143 | x
S5 | Rivet factor, two rivets per sleeve (pull only) | 16.723 | x
S6 | Tang tear-out factor above the shear pin hole | 43.662 | x
S7 | Ring bending stress, pulled at the tang against the far side | 36.443 | MPa
S8 | Ring bending factor on yield | 6.448 | x
S9 | Tang bending factor, quarter of the pull sideways | 6.505 | x
S10 | Crutch axle bending stress at 500 N line tension (M12, grade 4.6) | 91.699 | MPa
B1 | Float winder net lift | 1.257 | kg
B2 | Ring and cord, weight in water | 0.603 | kg
B3 | Reserve: lift over ring and cord | 2.085 | x
B4 | Ring, cord and jigging weight, weight in water (the float does not hold this) | 1.577 | kg
T1 | Workshop time for one kit, one smith (estimate) | 8.083 | h | R9 | at risk
C1 | Parts cost of one kit (prototype prices) | 95.5 | USD
C2 | Prototype run: three aluminium kits, one bamboo pole set and 2 m of calibration wire | 299.5 | USD
C3 | Value-engineering target (project.yaml) | 2000.0 | USD
C4 | Prototype run under the value-engineering target by | 1700.5 | USD
C5 | Pole, sleeves and rivets, share of the kit cost | 30.366 | %
C6 | Galvanising, share of the kit cost | 12.565 | %
C7 | Gunwale crutch, share of the kit cost | 12.565 | %
V1 | Bamboo pole: three culm sections, two ferrules and bolts | 2.176 | kg
V2 | Aluminium pole it replaces: sections, sleeves, rivets and grip cap | 2.565 | kg
V3 | Carried kit, bamboo local variant (crutch on the canoe, weight at the landing) | 3.894 | kg | R7 | met
V4 | Euler buckling load of the bamboo pole, pinned ends, E 15 GPa | 517.632 | N
V5 | Bamboo pole buckling factor over the top of the pin band (push) | 1.492 | x
V6 | Bamboo pole buckling factor if E is 10 GPa (low end) | 0.995 | x
V10 | Culm bend test: largest sag at mid-span, 50 N (5 kg) hung at the middle of a 1.4 m span, for E 15 GPa | 2.88 | mm
V7 | Crutch and jigging weight with their galvanising, saving per kit when one set serves five canoes | 17.6 | USD
V8 | Parts cost of one bamboo local variant kit, crutch and weight shared by five canoes | 54.9 | USD | R10 | not met
V9 | Parts cost of one aluminium prototype kit | 95.5 | USD | R10 | not met
N1 | Carried kit, aluminium prototype with 32 x 1.6 pole tube in place of 32 x 2 | 3.863 | kg
N2 | Buckling factor of a 32 x 1.6 aluminium pole over the top of the pin band | 1.837 | x
O11 | Light pin, 1.4 mm wire: nominal rating | 147.781 | N
L1 | small dugout, light pin: displacement | 280.0 | kg
L2 | small dugout, light pin: metacentric height GM | 0.149 | m
L3 | small dugout, light pin: freeboard; heel that puts the gunwale under | 299.158 | mm
L4 | small dugout, light pin: gunwale immersion angle | 38.581 | deg
L5 | small dugout, light pin: heel when the pin breaks at the top of its band, kneeling | 12.239 | deg | R3 | outside the 7 m rule (SMR-DDR-003)
L6 | small dugout, light pin: heel when the pin breaks at the top of its band, standing | 16.85 | deg | R3 | outside the 7 m rule (SMR-DDR-003)
L7 | small dugout, light pin: pole pull that heels the canoe 5 deg, kneeling | 53.439 | N
L8 | small dugout, light pin: pole pull that heels the canoe 5 deg, standing | 37.431 | N

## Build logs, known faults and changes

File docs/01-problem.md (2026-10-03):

---
doc_id: SMR-PRB-001
title: StumpRider problem statement
project: StumpRider
doc_type: Problem statement
version: "0.2"
status: Draft
date: '2026-10-03'
author: Amish Chadha
license: CERN-OHL-S-2.0
revisions:
- version: "0.1"
  date: '2026-09-30'
  author: Amish Chadha
  change: Initial scaffold
- version: "0.2"
  date: '2026-10-03'
  author: Amish Chadha
  change: TRL 2 update; design canoe and snag cases stated, budget written as a value-engineering target, open questions settled or moved to the design decisions register, first co-design candidates, safety section
---

# StumpRider problem statement

When a gillnet snags on a drowned tree, the crew has three choices: cut the net, pull until something gives, or send someone down. On Lake Volta that someone is often a child. StumpRider is a hand tool that gives the crew a fourth choice from the canoe.

> **Safety:** The tool exists so that nobody enters the water. It must never be presented as a reason to keep children on boats, and it never replaces a life jacket. Pulling on a snag from a narrow canoe can heel it; the shear pin limits that pull, and the crew cuts the net rather than risk a capsize.

## The problem

Child labour studies of Lake Volta list diving to disentangle nets from tree stumps among the tasks children do, alongside paddling, bailing and pulling nets, and name drowning and net entanglement as major dangers ([ILAB](https://www.dol.gov/sites/dolgov/files/ILAB/CHILD%20LABOUR%20IN%20VOLTA%20LAKE%20FISHING%20STUDY%20REPORT%20-%20FINAL%20REPORT.pdf)). Reporting on trafficked children describes boat masters forcing children who cannot swim to dive to the bottom of the lake ([CBS News, 2021](https://www.cbsnews.com/news/ghana-lake-volta-child-slavery/)). The IJM 2024 study found 15 % of working children reported diving to retrieve nets ([IJM, 2024](https://ijmstoragelive.blob.core.windows.net/ijmna/documents/studies/2023-Fishing_Prevalence_Study_Report.pdf)).

Existing tools do not fit this job. Angling lure retrievers slide a weight or ring down a fishing line to knock a lure free, and the basic version was patented in 1967 and has long expired ([US3464138A](https://patents.google.com/patent/US3464138)); retail versions such as the Ott-O-Retriever work the same way ([Bass Pro Shops](https://www.basspro.com/p/knockout-fishing-ott-o-retriever)). They are sized for a monofilament line and a single lure, not a gillnet hooked over a branch. Underwater timber harvesting removes valuable trunks from the Volta Lake and improves navigation ([Wikipedia](https://en.wikipedia.org/wiki/Lake_Volta)), but it is slow and selective and leaves fishers with nothing to use today.

## Users and context

*Table 1. Users.*

| User | Need | Context |
| --- | --- | --- |
| Canoe crews and boat owners | Free a snagged net quickly without cutting it or sending anyone into the water | Dugout or plank canoes, two to five crew, gillnets set among drowned trees |
| Child protection and anti-trafficking NGOs | A tangible tool to distribute with awareness and rescue programmes | Landing sites and fishing villages along the lake |
| Fisheries officers and fisher associations | A safe-practice measure they can promote and help make locally | District fisheries offices, landing-site committees |
| Village blacksmiths and carpenters | Drawings they can follow with hand tools and local stock | Small workshops with a stick welder, a drill and a vice |

## Operating environment

- Warm fresh water, surface temperature typically above 25 °C (77 °F) (estimate), with poor underwater visibility.
- Snags from just below the surface to several metres down; design target 6 m (20 ft) of snag depth.
- Worked from narrow wooden canoes that are easy to roll; the operator kneels near the bow.
- Design canoe for the calculations (SMR-CAL-001): a paddled plank canoe 8 m (26 ft) long, 1.1 m (3.6 ft) wide at the waterline, with three crew. A small dugout of 5.5 m with two crew is checked as the hard case.
- Wind chop, rain and sun; tools left wet in the canoe bottom for months.
- No power, no workshop on the water; repairs happen at the landing site.

## Snag cases

Two cases set the design (SMR-CAL-001, section 4):

- **Hooked:** the net is caught over a branch, about half a turn of contact. Lifting it off takes about 80 to 130 N (18 to 29 lbf) on paper if the crew slackens the line while the operator lifts.
- **Wrapped:** the net has wound once round the branch. Friction grows so fast with each turn that lifting it straight off would need 370 N to more than 2 kN; it has to be worked back round the branch first, or cut.

How often each case occurs is not known; it is the first thing the co-design partner is asked.

## Constraints

- Value-engineering target: USD 2,000 for the prototype work (a hypothetical control target that keeps the design on a value-engineering lens, not a spending limit).
- Unit parts cost target below USD 40 per kit (R10), so that boat owners and NGOs can afford it.
- Buildable with hand tools, a small welder or forge, and locally available steel bar, aluminium or bamboo, and cord.
- Must never require anyone to enter the water.
- The pull transmitted to the canoe must stay below a level that heels it dangerously, which sets the shear-pin rating.
- Open hardware under CERN-OHL-S-2.0; documentation under the lab defaults.

## Out of scope

- Removing or harvesting drowned trees.
- Changing gillnet design or fishing practice beyond snag release.
- Enforcement, rescue or rehabilitation of trafficked children; the tool supports that work but does not replace it.
- Powered winches or capstans on the canoe.

## Prior work

*Table 2. Prior work.*

| Prior work | What it does | Gap for these users | Source |
| --- | --- | --- | --- |
| US3464138A, device for releasing a snagged fishing lure (1969, expired) | An openable ring with a weight that is clipped round a fishing line, slid down to the lure and jigged to free the hooks | Sized for a single line and lure; no way to lift a net off a branch or limit the pull on a small canoe | [link](https://patents.google.com/patent/US3464138) |
| Retail lure retrievers (for example Knockout Ott-O-Retriever) | A weight that attaches to the fishing line and slides down to knock a snagged lure free | Works on a light line and a lure, not a gillnet hooked on a trunk | [link](https://www.basspro.com/p/knockout-fishing-ott-o-retriever) |
| Underwater timber harvesting on Volta Lake | Commercial removal of submerged hardwood, which also improves navigation | Slow, selective and far from most fishing grounds; gives fishers nothing to use today | [link](https://commons.wmu.se/cgi/viewcontent.cgi?article=1009&context=all_dissertations) |

## Co-design

A child-protection or anti-trafficking NGO already working with fishing communities on Lake Volta, paired with a fisher association or landing-site committee, so that the tool is tested with crews who actually set nets among stumps and handed out alongside existing protection work. First candidates to approach (none approached yet): Challenging Heights, a Ghanaian NGO working against child trafficking in Volta fishing; a landing-site committee on the Volta Lake through the Fisheries Commission's Volta zone office; and a Ghanaian university fisheries department for the staged-snag trials.

## Questions settled at TRL 2

The open questions of version 0.1 are settled in the design decisions register (SMR-DEC-001) or carried there as items to confirm:

- Safe side pull and shear-pin rating: 300 N nominal (256 to 347 N), set against the design canoe (decision D3); small dugouts are a decision for Amish (SMR-REQ-001, R3).
- Wrapped nets: a ring alone cannot lift a wrapped net within the pin rating (decision for Amish, R1).
- Fork or hook head: kept as an option for the R1 decision; the ring is the prototype head.
- Distribution with child protection work: through the co-design partner, never sold or handed out alone (decision D9).
- Lake Kariba and other reservoirs: to confirm with the partner network; it does not change the prototype.

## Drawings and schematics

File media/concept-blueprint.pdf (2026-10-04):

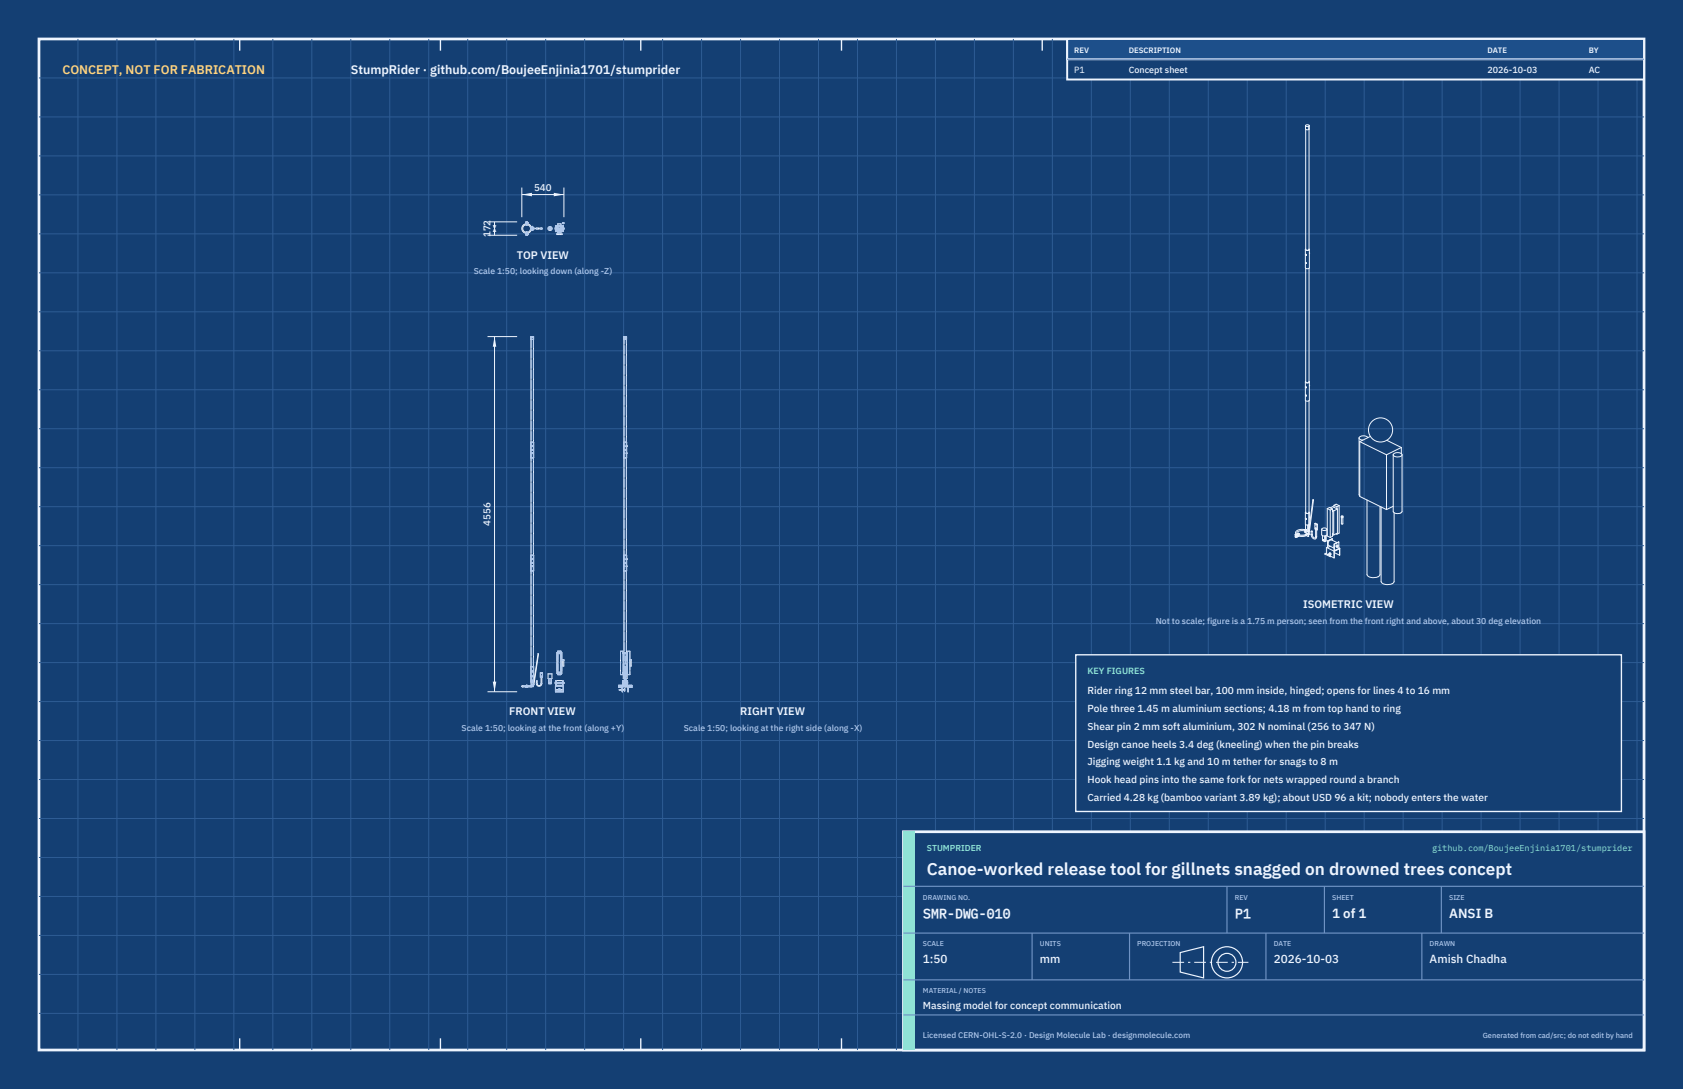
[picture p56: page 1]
CONCEPT, NOT FOR FABRICATION; StumpRider · github.com/BoujeeEnjinia1701/stumprider; FRONT VIEW; TOP VIEW; RIGHT VIEW; ISOMETRIC VIEW; REV; DESCRIPTION; DATE; Concept sheet; STUMPRIDER; github.com/BoujeeEnjinia1701/stumprider; DRAWING NO. SMR-DWG-010; REV P1; SHEET 1 of 1; SIZE ANSI B; SCALE 1:50; UNITS mm; PROJECTION; DRAWN Amish Chadha; Licensed CERN-OHL-S-2.0 · Design Molecule Lab · designmolecule.com; Generated from cad/src; do not edit by hand

Scale 1:50; looking down (along -Z)

Not to scale; figure is a 1.75 m person; seen from the front right and above, about 30 deg elevation

KEY FIGURES
Rider ring 12 mm steel bar, 100 mm inside, hinged; opens for lines 4 to 16 mm
Pole three 1.45 m aluminium sections; 4.18 m from top hand to ring
Shear pin 2 mm soft aluminium, 302 N nominal (256 to 347 N)
Design canoe heels 3.4 deg (kneeling) when the pin breaks
Jigging weight 1.1 kg and 10 m tether for snags to 8 m
Hook head pins into the same fork for nets wrapped round a branch
Carried 4.28 kg (bamboo variant 3.89 kg); about USD 96 a kit; nobody enters the water

Scale 1:50; looking at the front (along +Y)

Scale 1:50; looking at the right side (along -X)

Canoe-worked release tool for gillnets snagged on drowned trees concept

MATERIAL / NOTES
Massing model for concept communication

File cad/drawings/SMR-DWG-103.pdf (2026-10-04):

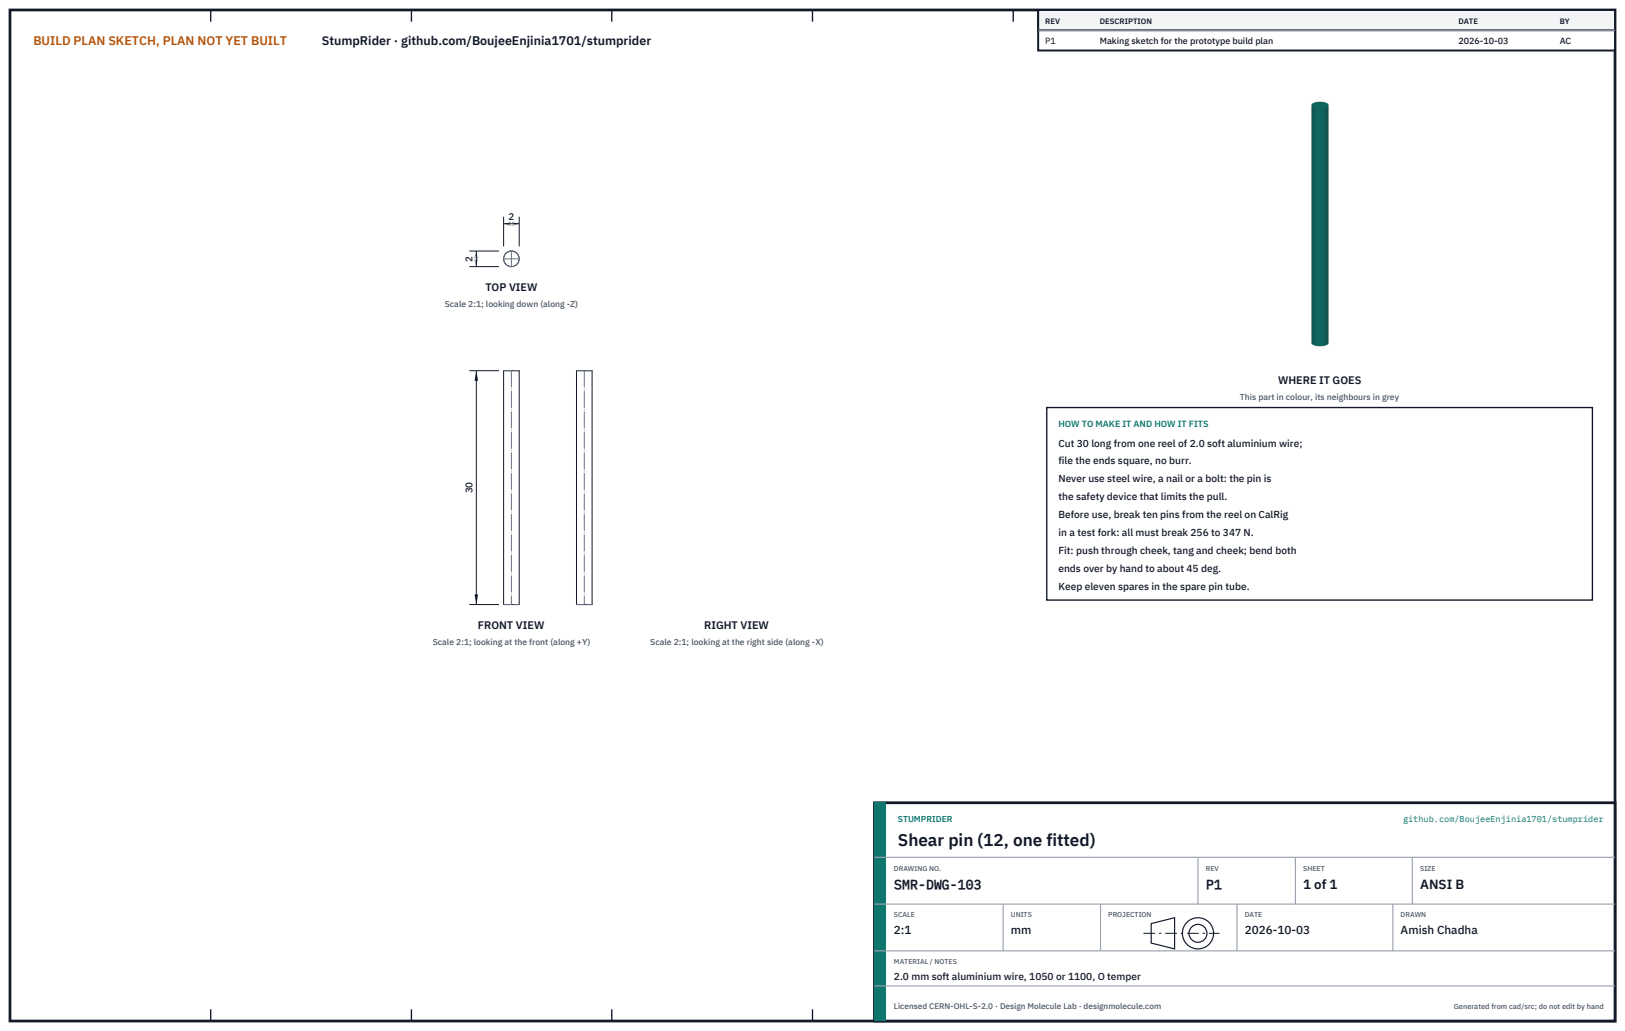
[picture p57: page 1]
BUILD PLAN SKETCH, PLAN NOT YET BUILT; StumpRider · github.com/BoujeeEnjinia1701/stumprider; FRONT VIEW; TOP VIEW; RIGHT VIEW; REV; DESCRIPTION; DATE; Making sketch for the prototype build plan; STUMPRIDER; github.com/BoujeeEnjinia1701/stumprider; DRAWING NO. SMR-DWG-103; REV P1; SHEET 1 of 1; SIZE ANSI B; SCALE 2:1; UNITS mm; PROJECTION; DRAWN Amish Chadha; Licensed CERN-OHL-S-2.0 · Design Molecule Lab · designmolecule.com; Generated from cad/src; do not edit by hand

Scale 2:1; looking down (along -Z)

WHERE IT GOES

This part in colour, its neighbours in grey

HOW TO MAKE IT AND HOW IT FITS
Cut 30 long from one reel of 2.0 soft aluminium wire;
file the ends square, no burr.
Never use steel wire, a nail or a bolt: the pin is
the safety device that limits the pull.
Before use, break ten pins from the reel on CalRig
in a test fork: all must break 256 to 347 N.
Fit: push through cheek, tang and cheek; bend both
ends over by hand to about 45 deg.
Keep eleven spares in the spare pin tube.

Scale 2:1; looking at the front (along +Y)

Scale 2:1; looking at the right side (along -X)

Shear pin (12, one fitted)

MATERIAL / NOTES
2.0 mm soft aluminium wire, 1050 or 1100, O temper

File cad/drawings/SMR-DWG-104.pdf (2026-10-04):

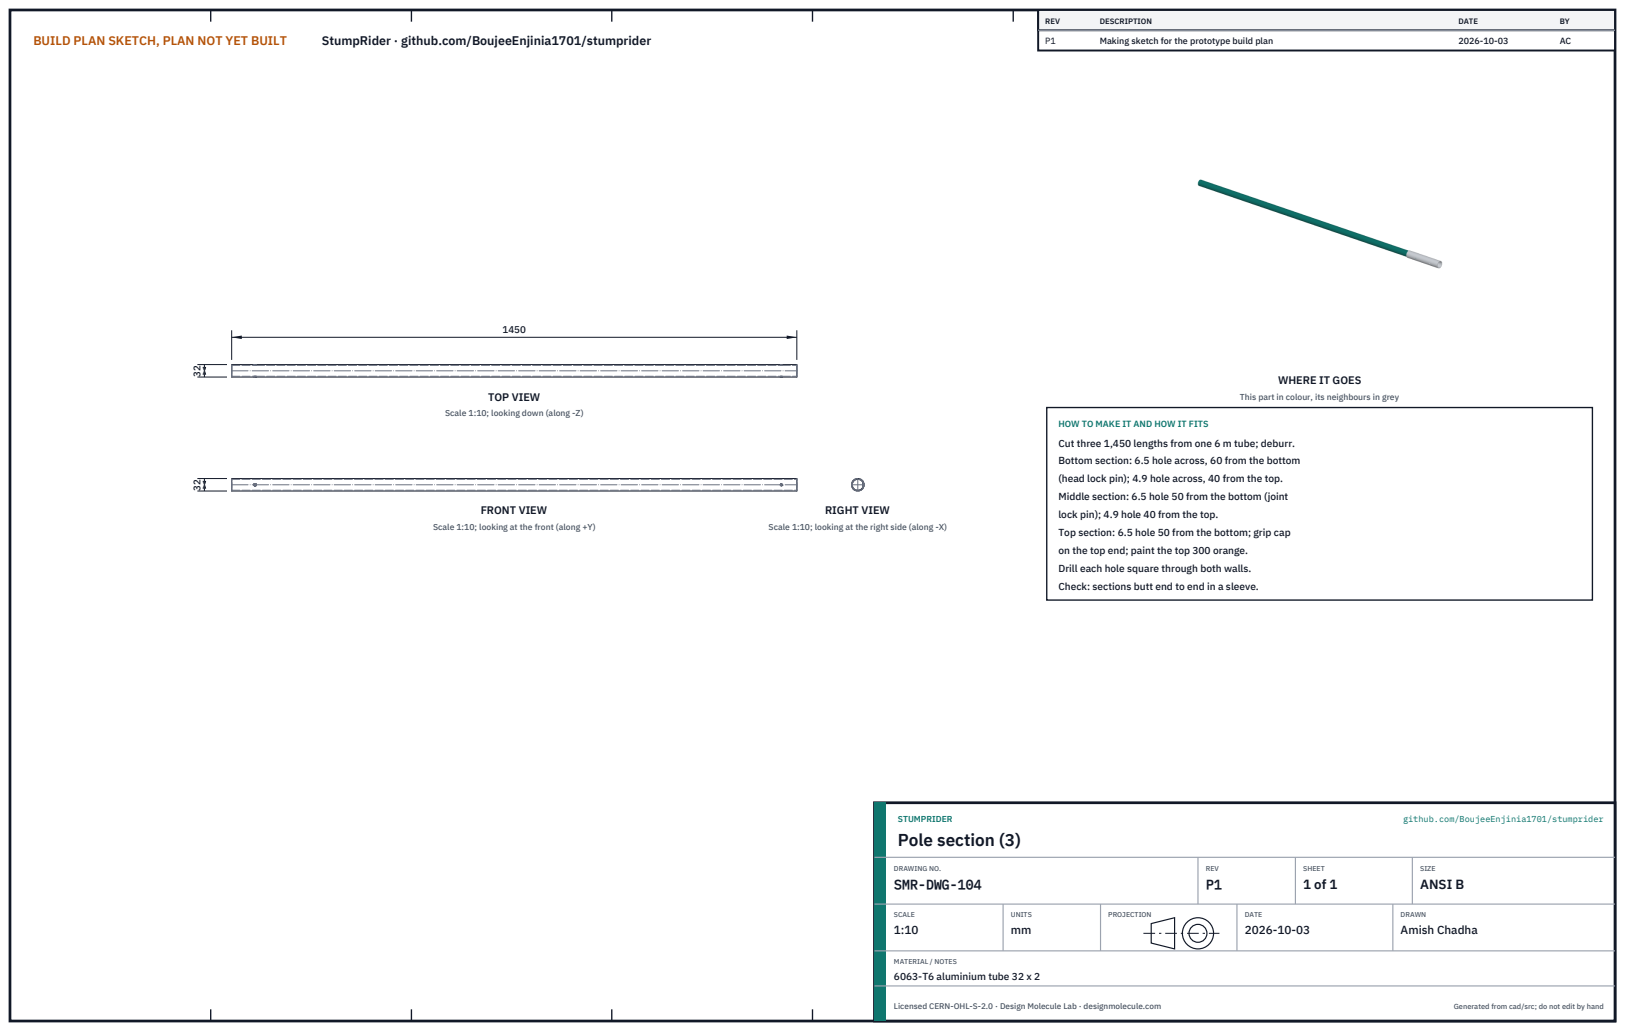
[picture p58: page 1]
BUILD PLAN SKETCH, PLAN NOT YET BUILT; StumpRider · github.com/BoujeeEnjinia1701/stumprider; FRONT VIEW; TOP VIEW; RIGHT VIEW; REV; DESCRIPTION; DATE; Making sketch for the prototype build plan; STUMPRIDER; github.com/BoujeeEnjinia1701/stumprider; Pole section (3); DRAWING NO. SMR-DWG-104; REV P1; SHEET 1 of 1; SIZE ANSI B; SCALE 1:10; UNITS mm; PROJECTION; DRAWN Amish Chadha; MATERIAL / NOTES 6063-T6 aluminium tube 32 x 2; Licensed CERN-OHL-S-2.0 · Design Molecule Lab · designmolecule.com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

WHERE IT GOES

This part in colour, its neighbours in grey

Scale 1:10; looking down (along -Z)

HOW TO MAKE IT AND HOW IT FITS
Cut three 1,450 lengths from one 6 m tube; deburr.
Bottom section: 6.5 hole across, 60 from the bottom
(head lock pin); 4.9 hole across, 40 from the top.
Middle section: 6.5 hole 50 from the bottom (joint
lock pin); 4.9 hole 40 from the top.
Top section: 6.5 hole 50 from the bottom; grip cap
on the top end; paint the top 300 orange.
Drill each hole square through both walls.
Check: sections butt end to end in a sleeve.

Scale 1:10; looking at the front (along +Y)

Scale 1:10; looking at the right side (along -X)

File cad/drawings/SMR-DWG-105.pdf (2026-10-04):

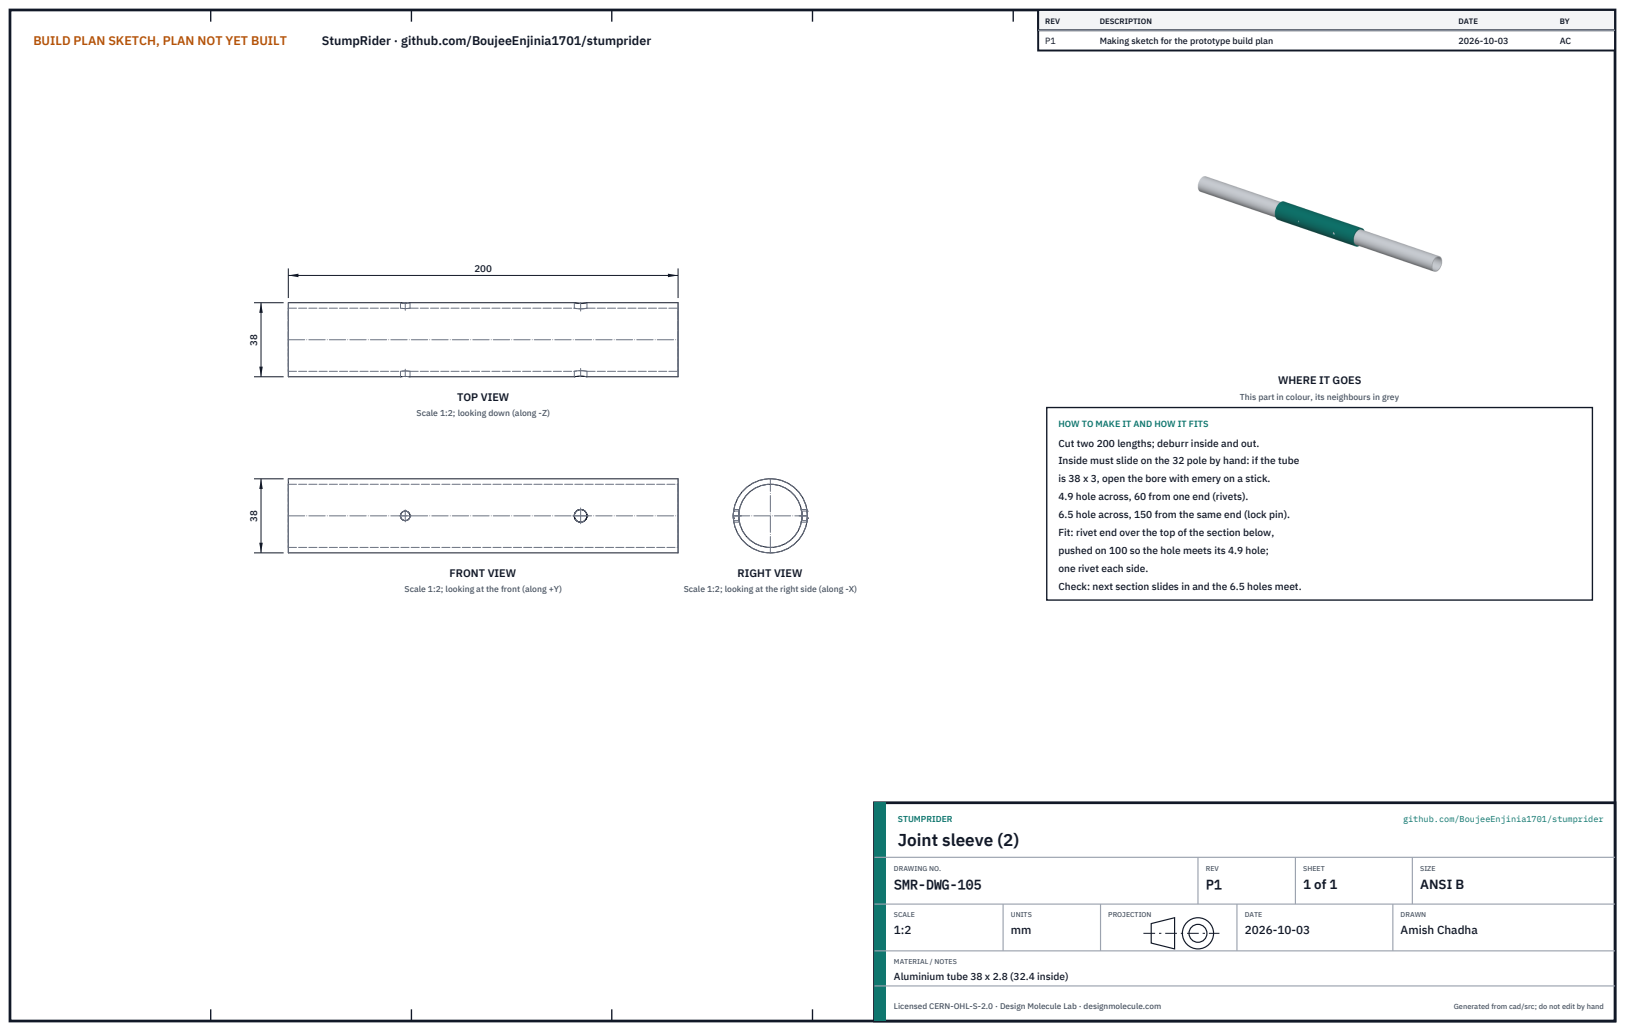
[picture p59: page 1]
BUILD PLAN SKETCH, PLAN NOT YET BUILT; StumpRider · github.com/BoujeeEnjinia1701/stumprider; FRONT VIEW; TOP VIEW; RIGHT VIEW; REV; DESCRIPTION; DATE; Making sketch for the prototype build plan; STUMPRIDER; github.com/BoujeeEnjinia1701/stumprider; Joint sleeve (2); DRAWING NO. SMR-DWG-105; REV P1; SHEET 1 of 1; SIZE ANSI B; SCALE 1:2; UNITS mm; PROJECTION; DRAWN Amish Chadha; Licensed CERN-OHL-S-2.0 · Design Molecule Lab · designmolecule.com; Generated from cad/src; do not edit by hand

WHERE IT GOES

This part in colour, its neighbours in grey

Scale 1:2; looking down (along -Z)

HOW TO MAKE IT AND HOW IT FITS
Cut two 200 lengths; deburr inside and out.
Inside must slide on the 32 pole by hand: if the tube
is 38 x 3, open the bore with emery on a stick.
4.9 hole across, 60 from one end (rivets).
6.5 hole across, 150 from the same end (lock pin).
Fit: rivet end over the top of the section below,
pushed on 100 so the hole meets its 4.9 hole;
one rivet each side.
Check: next section slides in and the 6.5 holes meet.

Scale 1:2; looking at the front (along +Y)

Scale 1:2; looking at the right side (along -X)

MATERIAL / NOTES
Aluminium tube 38 x 2.8 (32.4 inside)

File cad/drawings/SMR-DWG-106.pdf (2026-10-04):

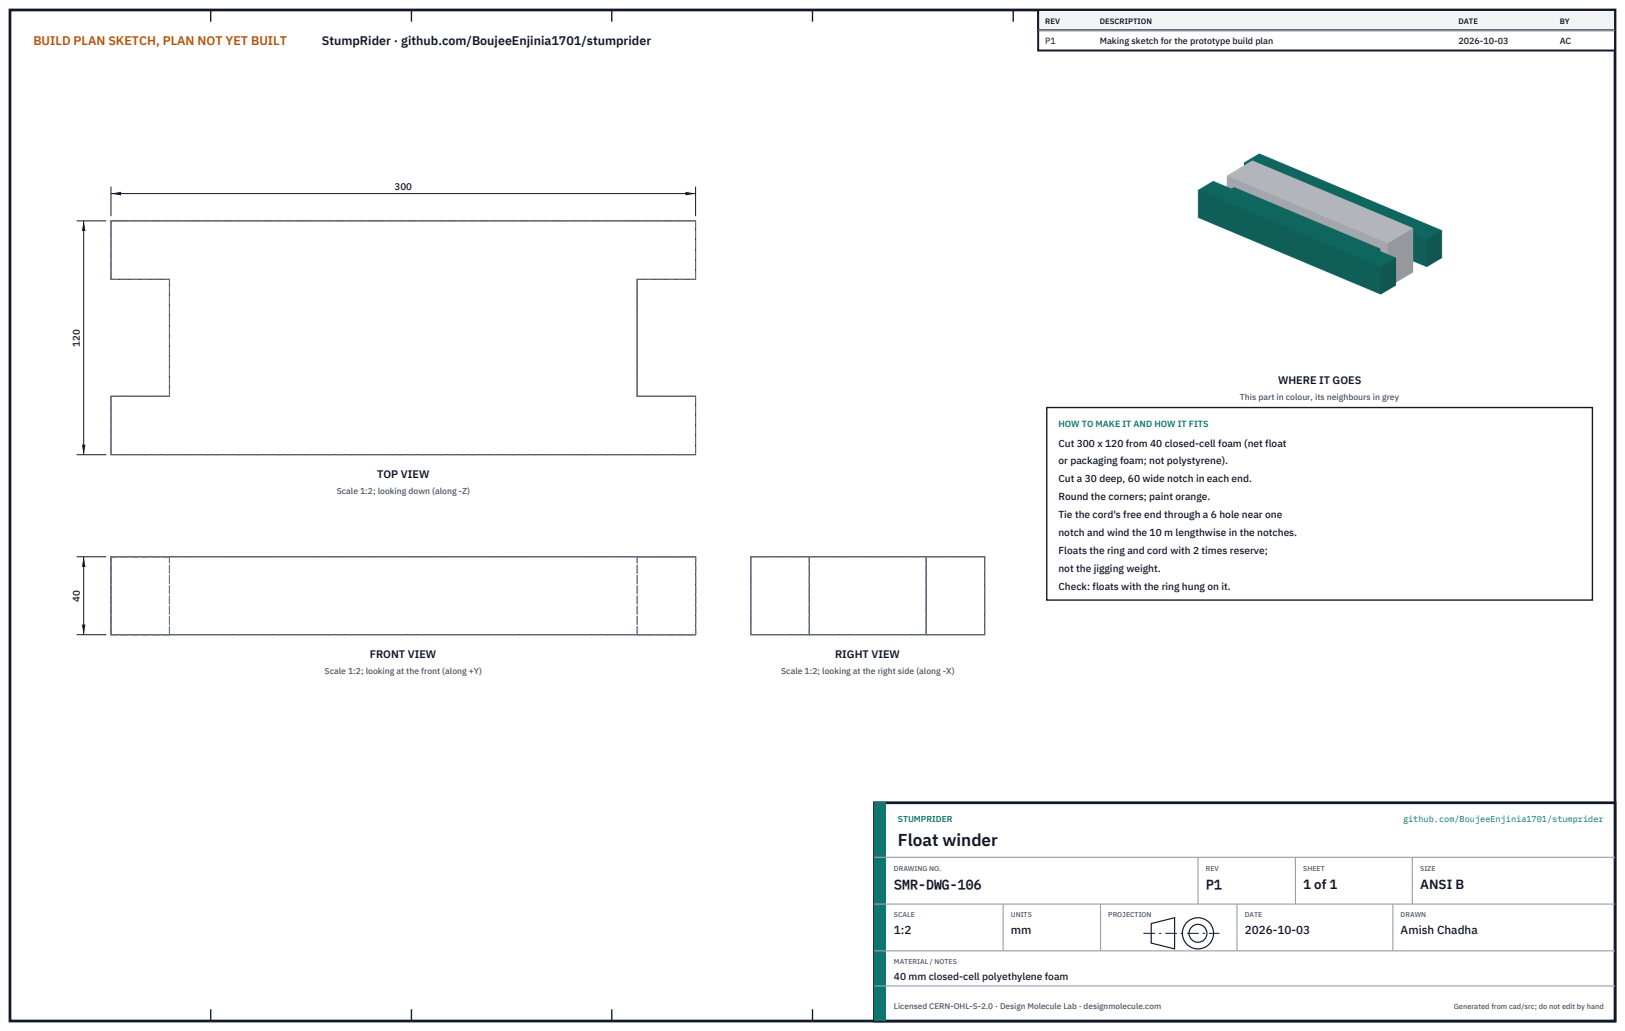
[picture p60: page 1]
BUILD PLAN SKETCH, PLAN NOT YET BUILT; StumpRider · github.com/BoujeeEnjinia1701/stumprider; FRONT VIEW; TOP VIEW; RIGHT VIEW; REV; DESCRIPTION; DATE; Making sketch for the prototype build plan; STUMPRIDER; github.com/BoujeeEnjinia1701/stumprider; Float winder; DRAWING NO. SMR-DWG-106; REV P1; SHEET 1 of 1; SIZE ANSI B; SCALE 1:2; UNITS mm; PROJECTION; DRAWN Amish Chadha; Licensed CERN-OHL-S-2.0 · Design Molecule Lab · designmolecule.com; Generated from cad/src; do not edit by hand

WHERE IT GOES

This part in colour, its neighbours in grey

HOW TO MAKE IT AND HOW IT FITS
Cut 300 x 120 from 40 closed-cell foam (net float
or packaging foam; not polystyrene).
Cut a 30 deep, 60 wide notch in each end.
Round the corners; paint orange.
Tie the cord's free end through a 6 hole near one
notch and wind the 10 m lengthwise in the notches.
Floats the ring and cord with 2 times reserve;
not the jigging weight.
Check: floats with the ring hung on it.

Scale 1:2; looking down (along -Z)

Scale 1:2; looking at the front (along +Y)

Scale 1:2; looking at the right side (along -X)

MATERIAL / NOTES
40 mm closed-cell polyethylene foam

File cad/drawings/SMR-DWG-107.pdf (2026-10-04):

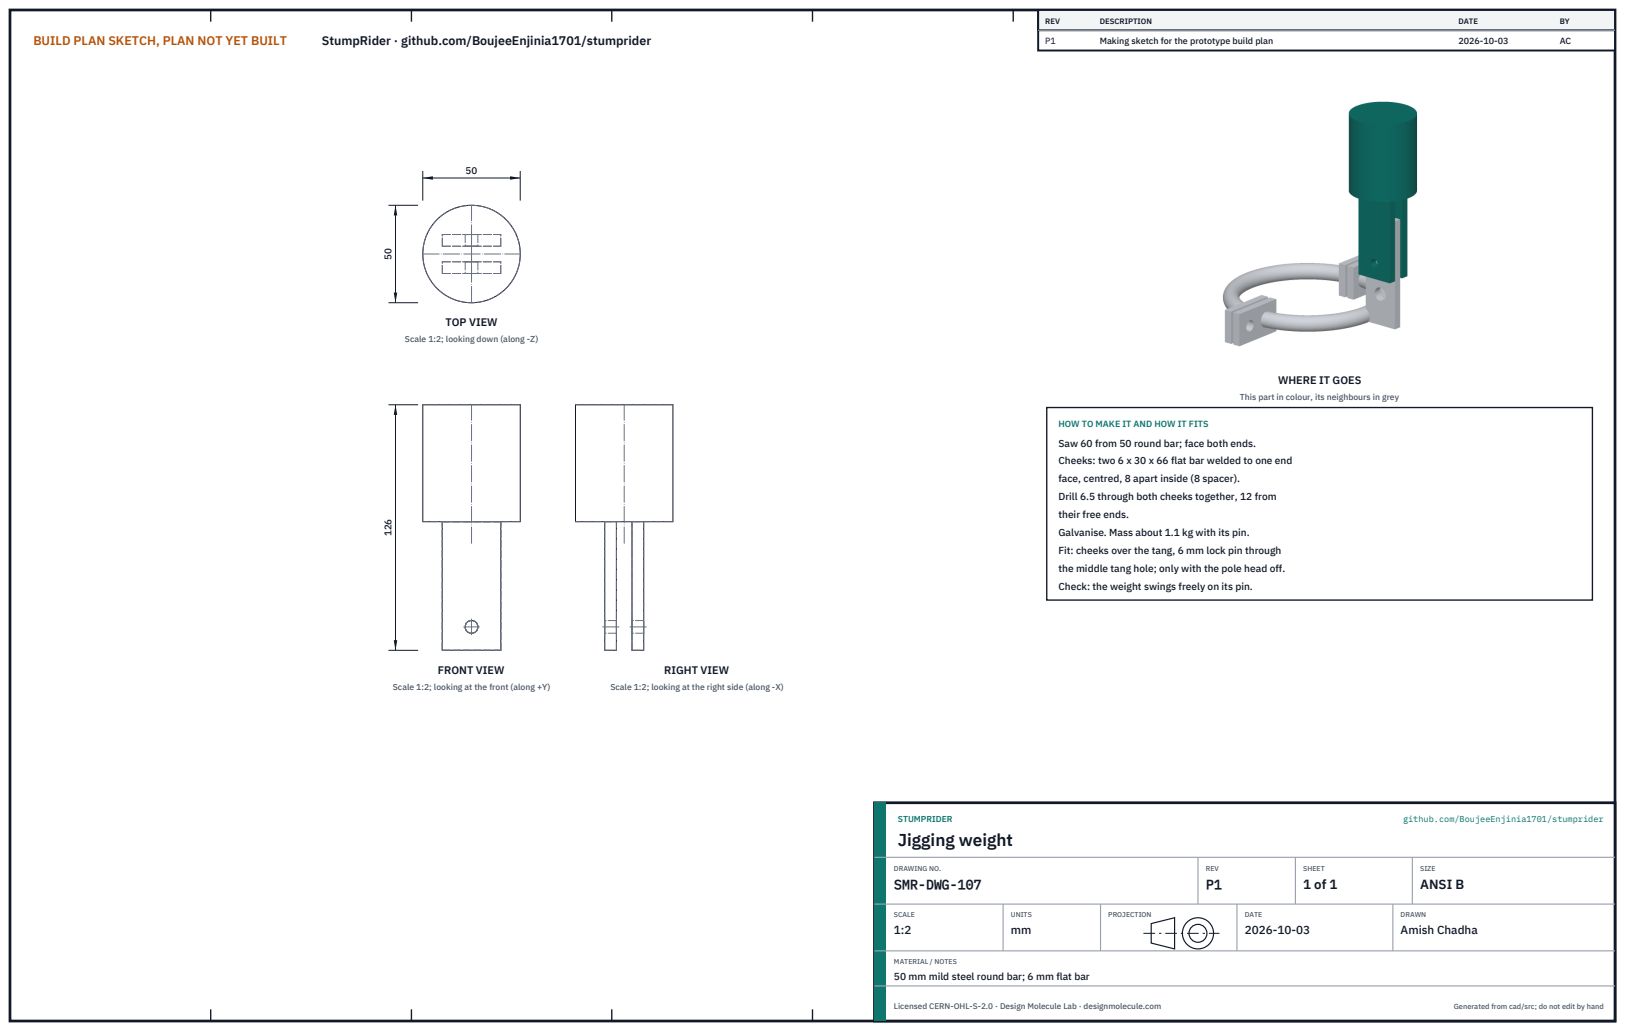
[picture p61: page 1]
BUILD PLAN SKETCH, PLAN NOT YET BUILT; StumpRider · github.com/BoujeeEnjinia1701/stumprider; FRONT VIEW; TOP VIEW; RIGHT VIEW; REV; DESCRIPTION; DATE; Making sketch for the prototype build plan; STUMPRIDER; github.com/BoujeeEnjinia1701/stumprider; Jigging weight; DRAWING NO. SMR-DWG-107; REV P1; SHEET 1 of 1; SIZE ANSI B; SCALE 1:2; UNITS mm; PROJECTION; DRAWN Amish Chadha; Licensed CERN-OHL-S-2.0 · Design Molecule Lab · designmolecule.com; Generated from cad/src; do not edit by hand

Scale 1:2; looking down (along -Z)

WHERE IT GOES

This part in colour, its neighbours in grey

HOW TO MAKE IT AND HOW IT FITS
Saw 60 from 50 round bar; face both ends.
Cheeks: two 6 x 30 x 66 flat bar welded to one end
face, centred, 8 apart inside (8 spacer).
Drill 6.5 through both cheeks together, 12 from
their free ends.
Galvanise. Mass about 1.1 kg with its pin.
Fit: cheeks over the tang, 6 mm lock pin through
the middle tang hole; only with the pole head off.
Check: the weight swings freely on its pin.

Scale 1:2; looking at the front (along +Y)

Scale 1:2; looking at the right side (along -X)

MATERIAL / NOTES
50 mm mild steel round bar; 6 mm flat bar

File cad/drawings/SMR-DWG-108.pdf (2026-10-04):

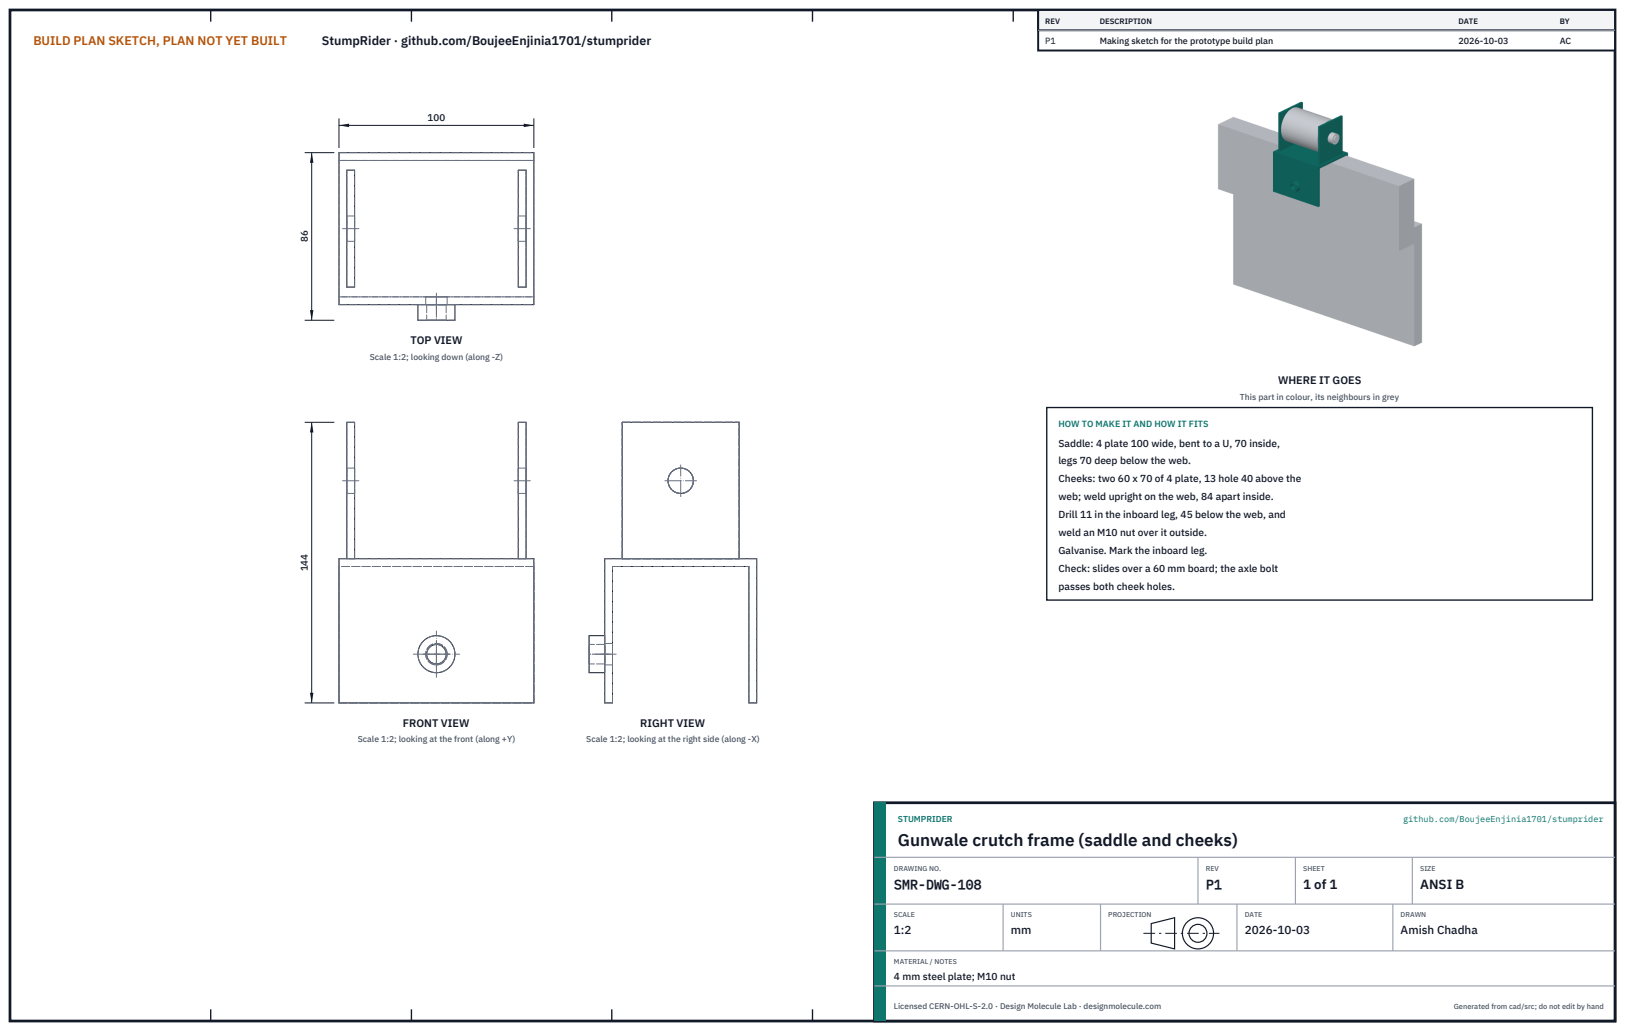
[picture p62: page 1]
BUILD PLAN SKETCH, PLAN NOT YET BUILT; StumpRider · github.com/BoujeeEnjinia1701/stumprider; FRONT VIEW; TOP VIEW; RIGHT VIEW; REV; DESCRIPTION; DATE; Making sketch for the prototype build plan; STUMPRIDER; github.com/BoujeeEnjinia1701/stumprider; DRAWING NO. SMR-DWG-108; REV P1; SHEET 1 of 1; SIZE ANSI B; SCALE 1:2; UNITS mm; PROJECTION; DRAWN Amish Chadha; Licensed CERN-OHL-S-2.0 · Design Molecule Lab · designmolecule.com; Generated from cad/src; do not edit by hand

Scale 1:2; looking down (along -Z)

WHERE IT GOES

This part in colour, its neighbours in grey

HOW TO MAKE IT AND HOW IT FITS
Saddle: 4 plate 100 wide, bent to a U, 70 inside,
legs 70 deep below the web.
Cheeks: two 60 x 70 of 4 plate, 13 hole 40 above the
web; weld upright on the web, 84 apart inside.
Drill 11 in the inboard leg, 45 below the web, and
weld an M10 nut over it outside.
Galvanise. Mark the inboard leg.
Check: slides over a 60 mm board; the axle bolt
passes both cheek holes.

Scale 1:2; looking at the front (along +Y)

Scale 1:2; looking at the right side (along -X)

Gunwale crutch frame (saddle and cheeks)

MATERIAL / NOTES
4 mm steel plate; M10 nut

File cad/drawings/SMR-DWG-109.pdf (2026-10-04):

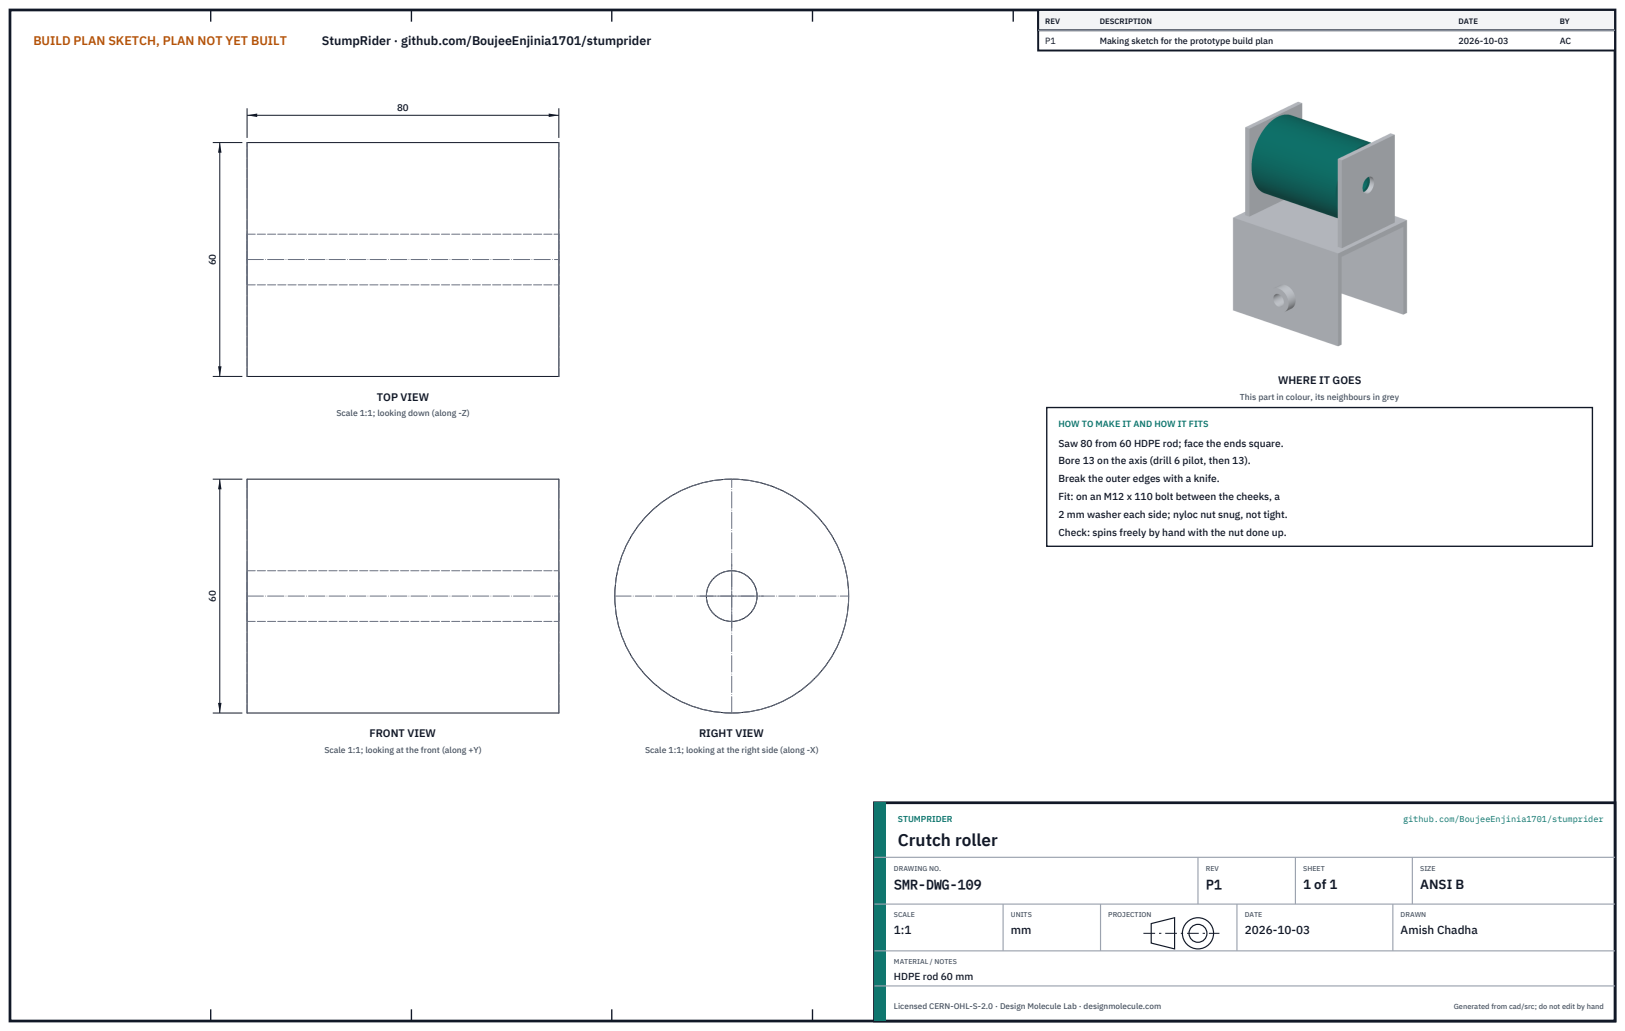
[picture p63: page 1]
BUILD PLAN SKETCH, PLAN NOT YET BUILT; StumpRider · github.com/BoujeeEnjinia1701/stumprider; FRONT VIEW; TOP VIEW; RIGHT VIEW; REV; DESCRIPTION; DATE; Making sketch for the prototype build plan; STUMPRIDER; github.com/BoujeeEnjinia1701/stumprider; Crutch roller; DRAWING NO. SMR-DWG-109; REV P1; SHEET 1 of 1; SIZE ANSI B; SCALE 1:1; UNITS mm; PROJECTION; DRAWN Amish Chadha; Licensed CERN-OHL-S-2.0 · Design Molecule Lab · designmolecule.com; Generated from cad/src; do not edit by hand

WHERE IT GOES

This part in colour, its neighbours in grey

Scale 1:1; looking down (along -Z)

HOW TO MAKE IT AND HOW IT FITS
Saw 80 from 60 HDPE rod; face the ends square.
Bore 13 on the axis (drill 6 pilot, then 13).
Break the outer edges with a knife.
Fit: on an M12 x 110 bolt between the cheeks, a
2 mm washer each side; nyloc nut snug, not tight.
Check: spins freely by hand with the nut done up.

Scale 1:1; looking at the front (along +Y)

Scale 1:1; looking at the right side (along -X)

MATERIAL / NOTES
HDPE rod 60 mm

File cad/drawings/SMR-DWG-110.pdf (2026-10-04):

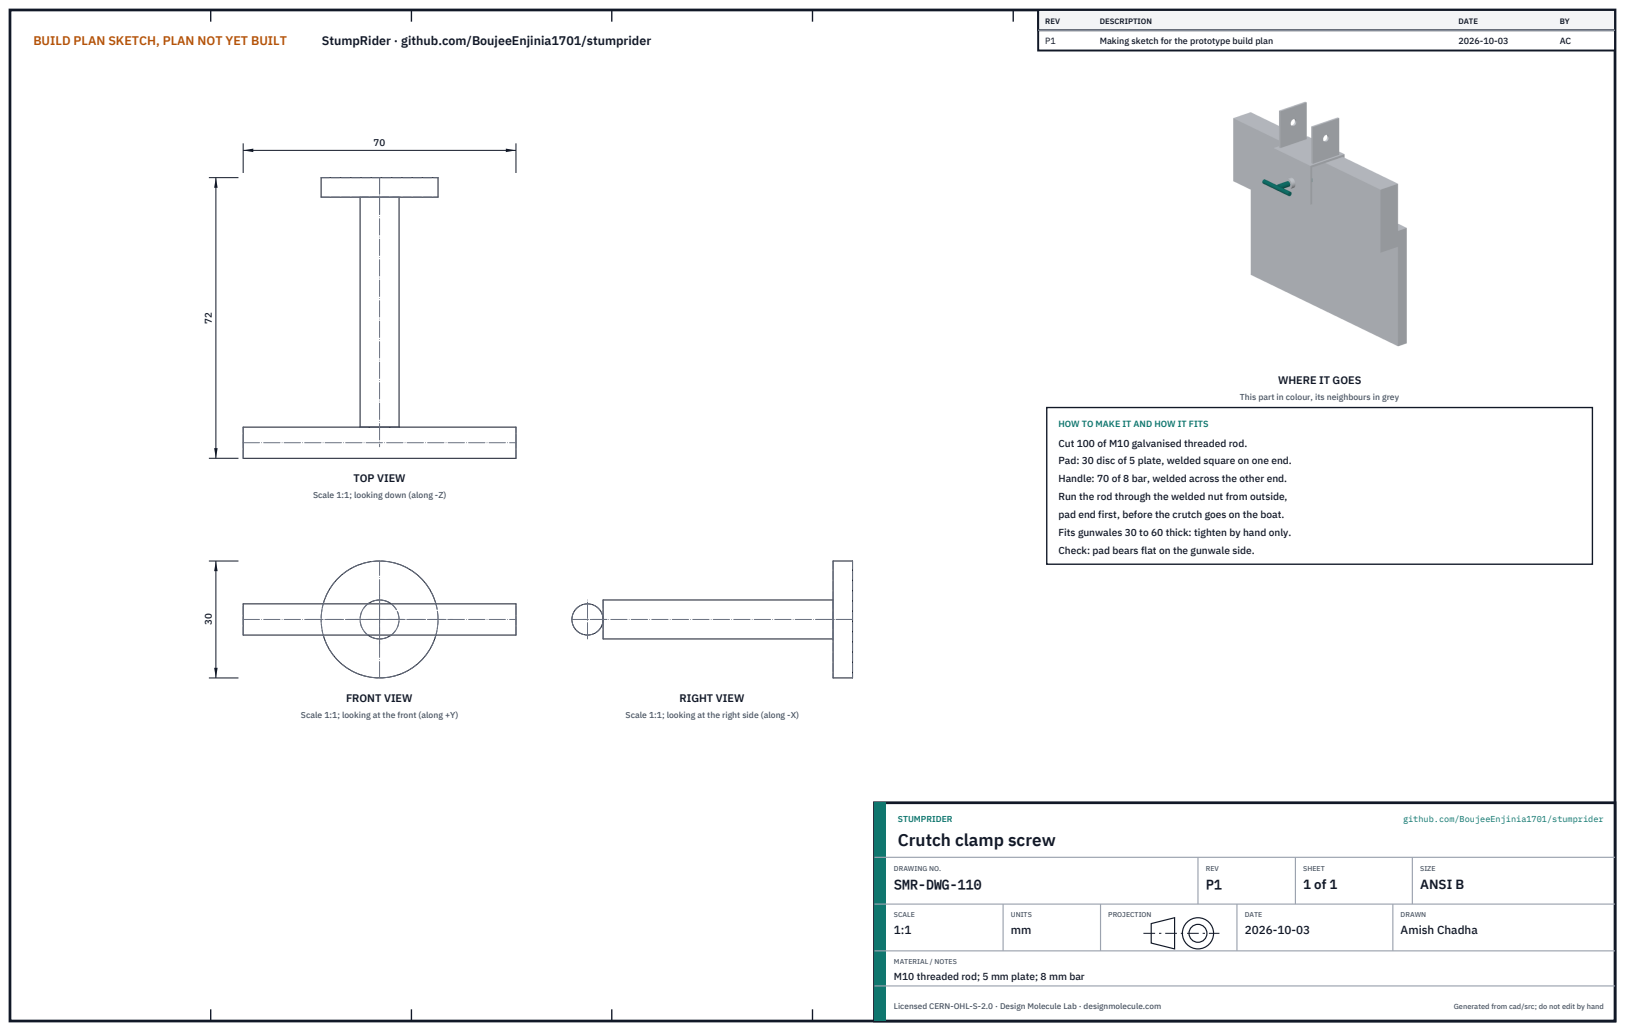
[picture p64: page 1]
BUILD PLAN SKETCH, PLAN NOT YET BUILT; StumpRider · github.com/BoujeeEnjinia1701/stumprider; FRONT VIEW; TOP VIEW; RIGHT VIEW; REV; DESCRIPTION; DATE; Making sketch for the prototype build plan; STUMPRIDER; github.com/BoujeeEnjinia1701/stumprider; DRAWING NO. SMR-DWG-110; REV P1; SHEET 1 of 1; SIZE ANSI B; SCALE 1:1; UNITS mm; PROJECTION; DRAWN Amish Chadha; Licensed CERN-OHL-S-2.0 · Design Molecule Lab · designmolecule.com; Generated from cad/src; do not edit by hand

WHERE IT GOES

This part in colour, its neighbours in grey

HOW TO MAKE IT AND HOW IT FITS
Cut 100 of M10 galvanised threaded rod.
Pad: 30 disc of 5 plate, welded square on one end.
Handle: 70 of 8 bar, welded across the other end.
Run the rod through the welded nut from outside,
pad end first, before the crutch goes on the boat.
Fits gunwales 30 to 60 thick: tighten by hand only.
Check: pad bears flat on the gunwale side.

Scale 1:1; looking down (along -Z)

Scale 1:1; looking at the front (along +Y)

Scale 1:1; looking at the right side (along -X)

Crutch clamp screw

MATERIAL / NOTES
M10 threaded rod; 5 mm plate; 8 mm bar

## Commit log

2026-10-03 StumpRider at TRL 3: constructable design (kit 1.7.0)
    Problem, concept and requirements; sizing calculations; CAD model, STEP and STL; general arrangement drawing; bill of materials; build plan with making sketches, joint close-ups and step pictures; design decisions register (design choices decided under Amish's 2026-10-03 pre-approval; requirement decisions open for Amish); TRL 2 and TRL 3 review; photoreal renders and storefront card. Private until Amish opens it.
    [bom.csv, crutch-roller.stl, float-winder.step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]
2026-10-04 Carry Amish's round 2 requirement decisions into the design
    Amish approved all 47 recommendations on 2026-10-03 ("i approve all of the 47 recommendations provided by you. Execute them."). Each repo gains a decision record (DDR-003, or the next free number for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
    [bom-local-variant.csv, bom.csv, float-winder.step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]
2026-10-04 Carry Amish's round-2 and round-3 decisions into the design
    Amish approved all 46 round-2 recommendations ("i agree with all the 46 recommendations you provided. please proceed.") and all round-3 recommendations ("For round 3, I agree with all your proposed r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
    [bamboo-pole-variant.step, bom-bamboo-variant.csv, bom.csv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]
2026-10-28 Kit 1.9.1 upgrade: pipeline documents and detailed CAD for every option
    Kit 1.9.1 installed (.kit, CLAUDE.md, .claude/commands). Kit 1.8 pipeline: STEM check with fixes under the 2026-10-23 standing instruction, concept options with the current design as option A, URS, PRS, generated RTM, REG, FEA, RSK with design FMEA, MKT, PLN and DDR; kit 1.9 D3 model of every option passing cad/fidelity.json; independent review recorded in the STEM check. Amish's 2026-10-25 decisions recorded where he approved a recommendation; all others proposed, awaiting Amish. Product renders and the options picture follow in a later commit where not yet included.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
2026-10-29 Add Cycles product renders and the concept options picture
    Blender Cycles renders of the kit 1.9.1 model, rendered on Amish's Mac and captioned; media/options.png from the D3 option models (this also clears the failing docs check, which needs the picture); cards and PDFs rebuilt. The options picture labels option A as the current design unless project.yaml records Amish's choice.
2026-10-29 Add the concept options picture rendered from the D3 option models
    media/options.png from Blender Cycles panels of every option, rendered on Amish's Mac; the label reads CURRENT DESIGN unless project.yaml records Amish's choice. Clears the docs check, which needs th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

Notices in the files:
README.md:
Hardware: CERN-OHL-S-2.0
